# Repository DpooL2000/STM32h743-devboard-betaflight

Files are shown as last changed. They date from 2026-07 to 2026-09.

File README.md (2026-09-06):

# STM32H743 Flight Controller (Betaflight Target)

This repository provides an open-source engineering blueprint, custom target files, and a 4-layer hardware carrier board design to run standard Betaflight firmware on a generic **DevEBox STM32H743VIT6 development board**. 

Unlike commercial flight controllers that limit you to pre-configured layouts, utilizing a standard industrial developer board breaks open full control of the silicon. This project serves as a definitive architectural guide to overcoming severe bare-metal implementation bugs, remapping timers for advanced multi-rotor and actuator configurations, and running ultra-low latency PID loops on a highly affordable H7 platform.

## Hardware Architecture Manifest

<p align="center">

</p>

The target configuration files provided here are explicitly tailored and tested against the following component topology and hardware pin allocation mapping:

* **Microcontroller Core:** STM32H743VIT6 (ARM Cortex-M7 running at a 480MHz bus clock).
* **Primary IMU (SPI1):** BMI160 Gyro/Accelerometer module routed to native SPI1 pins:
  * `PA4` (Chip Select / CS)
  * `PA5` (SCK), `PA6` (MISO / SDI), `PA7` (MOSI / SDO)
  * Dedicated `PC4` EXTI hardware interrupt line synchronization.
* **Secondary IMU (SPI2):** BMI160 Gyro/Accelerometer module mapped onto isolated native SPI2 pins:
  * `PB12` (Chip Select / CS)
  * `PB13` (SCK), `PB14` (MISO / SDI), `PB15` (MOSI / SDO)
  * Dedicated `PD10` EXTI hardware interrupt line synchronization.
* **Barometer (I2C1):** BMP280 module routed to `PB8` (SCL) and `PB9` (SDA), configured via hardware jumpers on the breakout module to default I2C Address `0x76`.
* **Blackbox Telemetry:** High-speed onboard SDIO MicroSD card slot combined with an onboard QSPI external flash memory layer (`W25Q64JV`):
  * **SDIO (SDMMC1):** `PC12` (CK), `PD2` (CMD), `PC8` (D0), `PC9` (D1), `PC10` (D2), `PC11` (D3). Card detection is handled via software polling (`SDCD_PIN` set to `NONE`).
  * **QSPI:** `PB2` (CLK), `PB6` (CS), `PD11` (IO0), `PD12` (IO1), `PE2` (IO2), `PD13` (IO3).
* **Power Supply Module Integration (GM V1.0):** Integrated hardware telemetry lines from the buck-regulated external power module routed directly to the microcontroller's high-precision 16-bit ADC peripheral interface:
  * **Voltage Sensing (V_SENS):** Routed to analog input pin `PC1` (`ADC_VBAT_PIN`).
  * **Current Sensing (I_SENS):** Routed to analog input pin `PC0` (`ADC_CURR_PIN`).
* **Actuator Layout & Communications Matrix:**
  * **Motors (1–8):** `PA0` (Motor 1), `PA1` (Motor 2), `PA2` (Motor 3), `PA3` (Motor 4), `PB0` (Motor 5, timer remapped), `PB1` (Motor 6, timer remapped), `PD5` (Motor 7), `PD6` (Motor 8).
  * **Servos (1–4):** `PE5` (Servo 1), `PE6` (Servo 2), `PE1` (Servo 3, timer remapped), `PA15` (Servo 4, timer remapped).
  * **Serial Peripherals:** `UART1` (`PA9` TX, `PA10` RX) dedicated to Serial RX; `UART3` (`PD8` TX, `PD9` RX) assigned to ESC Telemetry; `UART6` (`PC6` / `PC7`) and `UART7` (`PE8` / `PE7`) exposed for general telemetry/VTX expansion.
  * **Peripherals:** Beeper output assigned to `PC2` (inverted configuration).

## System Layout & Renderings

**You can solder through hole Devboard to the SMD pads of this breakout board** giving you clear explansion over configured pins, Eight through hole pads have been left on the breakout board that you can align the Devboard on top of breakout board. and similarly solder the BMI160, BMP280 GY board on the breakout board make the work much easy, Though i havent route the circuit for each sensor on the breakout board itself, you can easily do it if you want, or you can just go with GY boards!!!. 

<p align="center">
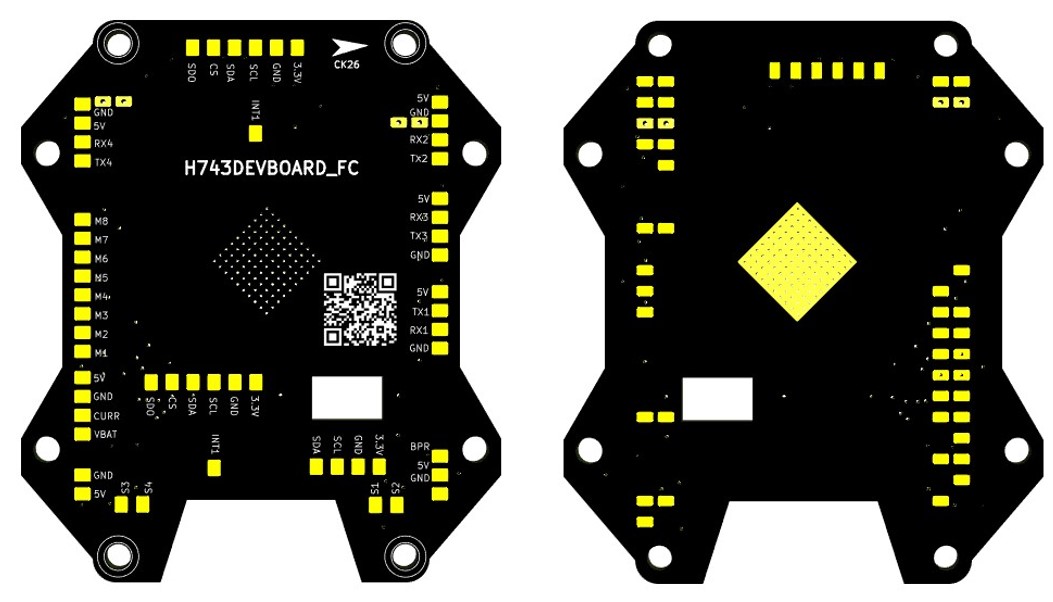
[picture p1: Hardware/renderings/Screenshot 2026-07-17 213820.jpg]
Carrier Board Layout

</p>

Detail guide on how the changes have been made is documented below, you can merge standard betaflight source code files with this. The project layout separates the custom hardware implementation from the localized Betaflight firmware tree structure as follows:

```text
├── Hardware/                      # Physical schematic and layout assets
│   ├── KiCad_Source/              # Raw .kicad_sch and .kicad_pcb project files
│   └── Renderings                 # Board images, schematics, and design references
|
├── STM32h743-devboard-betaflight/ # Target firmware deployment root
│   ├── src/                       # Localized Betaflight source tree overlays
│   │   ├── config/
│   │   │   └── configs/
│   │   │       └── DEVBOARD/
│   │   │           └── config.h   # Master firmware target pin mapping definitions
│   │   ├── main/
│   │   │   ├── drivers/
│   │   │   │   └── accgyro/
│   │   │   │       └── pios_bmi160.c
│   │   └── platform/
│   │       └── STM32/
│   │           └── startup/
│   │               └── system_stm32h7xx.c
```

---

# 1. Bare-Metal Hardware Troubleshooting

Bringing Betaflight up on standard industrial development boards reveals discrepancies between consumer flight controllers and raw silicon layouts. Below is the technical documentation of the critical bare-metal failures encountered during hardware debugging, along with their permanent firmware solutions.

### Bug 1.1: 25MHz HSE Crystal & PLL1 Clock Configuration Failures

**The Bug:**
Standard Betaflight STM32H7 codebases are optimized for 8MHz or 24MHz external crystals. The DevEBox hardware utilizes a 25MHz HSE. Applying default configuration multipliers caused the internal voltage-controlled oscillator (VCO) to hit 3000MHz, which drastically exceeds the 960MHz hardware limit. This caused the phase-locked loop engine to fail, triggering an infinite safety reset loop inside `HandleStuckSysTick()`.

**The Structural Fix:**
The internal clock structures (`pll1ConfigRevY` and `pll1ConfigRevV`) inside `src/platform/STM32/startup/system_stm32h7xx.c` must be rewritten to scale the 25MHz crystal safely:

```c
// Adjusted clock parameters for a stable 480MHz SYSCLK
pllConfig_t pll1ConfigRevV = {
    .clockMhz = 480,
    .m = 5,
    .n = 192,
    .p = 2,
    .q = 8,
    .r = 5,
    .vos = PWR_REGULATOR_VOLTAGE_SCALE0,
    .vciRange = RCC_PLL1VCIRANGE_2,
};
```

### Bug 1.2: Missing HSI48 Internal Oscillator & PLL3 USB Solution

**The Bug:**
To establish a stable USB Virtual COM Port (VCP), the STM32 USB peripheral requires a 48MHz clock stream. Betaflight natively attempts to activate the internal HSI48 oscillator. However, hardware debugging proved the DevEBox completely ignores `RCC_CR_HSI48ON` register writes, leaving the USB peripheral without a clock signal and failing to enumerate.

**The Structural Fix:**
Bypass the dead internal HSI48 circuit and synthesize a 48MHz USB clock using the primary 25MHz HSE crystal routed through the PLL3 engine.

Define the macro override in your local `config.h`:

```c
#define USE_USB_CLOCK_PLL3
```

Apply these specific division parameters inside the USB initialization block of `system_stm32h7xx.c` to step the 25MHz HSE down to an exact 48MHz envelope:

```c
PLL3M = 5,  // 25MHz HSE / 5 = 5MHz reference
PLL3N = 48, // 5MHz * 48 = 240MHz VCO3
PLL3Q = 5   // 240MHz VCO3 / 5 = 48MHz USB output clock
```

### Bug 1.3: Dual BMI160 Cold-Boot Lockout & DMA Collision

**The Bug:**
When booting two BMI160 gyroscopes simultaneously via SPI1 and SPI2, the secondary gyro regularly fails to lock DMA. 
1. **DMA Hijacking:** `DSHOT_BITBANG_1` was statically allocated to `DMA1 Stream 0`, forcing the H7 DMAMUX auto-allocator to starve `SPI1_TX` of a continuous stream, resulting in CPU-polling mode (missing the `dma` flag).
2. **State Variable Collision:** The driver code (`pios_bmi160.c`) utilized global state variables (`BMI160InitDone`). When Gyro 1 initialized, it set the variable to true, which caused Gyro 2 to completely bypass its configuration logic on cold boots.

**The Structural Fix:**
First, bypass the DMAMUX auto-allocator by hardcoding explicit DMA offsets in your local `config.h`:

```c
// Force dual-gyro initialization on boot
#define DEFAULT_GYRO_TO_USE          GYRO_CONFIG_USE_GYRO_BOTH

// Explicit SPI DMA Stream Offsets (Bypasses DMAMUX Auto-Allocation Collisions)
#define SPI1_TX_DMA_OPT              5  // Maps to DMA1 Stream 4
#define SPI1_RX_DMA_OPT              2  // Maps to DMA1 Stream 1
#define SPI2_TX_DMA_OPT              3  // Maps to DMA1 Stream 2
#define SPI2_RX_DMA_OPT              4  // Maps to DMA1 Stream 3
```

Second, eliminate the shared global states within the driver. Inside `src/main/drivers/accgyro/pios_bmi160.c`, delete the global boolean variables (`BMI160InitDone` and `BMI160Detected`) and replace the initialization functions with this independent configuration logic:

```c
uint8_t bmi160Detect(const extDevice_t *dev)
{
    // Toggle CS to activate SPI
    spiWrite(dev, 0xFF);
    delay(100); // Give SPI some time to start up

    // Check the chip ID
    if (spiReadRegMsk(dev, BMI160_REG_CHIPID) != 0xd1) {
        return MPU_NONE;
    }

    return BMI_160_SPI;
}

static void BMI160_Init(const extDevice_t *dev)
{
    /* Configure the BMI160 Sensor */
    if (BMI160_Config(dev) != 0) {
        return;
    }

    bool do_foc = false;
    /* Perform fast offset compensation if requested */
    if (do_foc) {
        BMI160_do_foc(dev);
    }
}
```

---

# 2. Firmware Source Tree Modification & Compilation Guide

To replicate this build and compile the custom DevEBox target, follow these exact modifications within the Betaflight source tree.

### 1. Target Directory Setup
Create a new directory named `DEVBOARD` inside `src/main/config/configs/`. 
Place your custom `config.h` files into this new folder.

### 2. Core Source Modifications
You must manually patch the following core Betaflight files to implement the bare-metal hardware fixes detailed in Section 1:

**File: `src/platform/STM32/startup/system_stm32h7xx.c`**
* Locate the `pll1ConfigRevY` and `pll1ConfigRevV` structures. Update the multipliers for the 25MHz HSE: set `.m = 25`, `.n = 400`, and `.p = 2`.
* Locate the USB clock configuration block. Comment out the `HSI48` initialization and insert the PLL3 dividers: `PLL3M = 5`, `PLL3N = 48`, and `PLL3Q = 5`.
* Locate the `SystemInit()` function and comment out the `memProtConfigure()` call to prevent early boot memory protection faults on this specific developer silicon.

**File: `src/main/drivers/accgyro/pios_bmi160.c`**
* Locate the `bmi160Detect()` and `BMI160_Init()` functions.
* Delete the `BMI160InitDone` and `BMI160Detected` global variables and paste the updated initialization block provided in Section 1.3 to ensure both gyros initialize independently and acquire DMA locks.

# 3. Compilation & Flashing

### Step 1: Clone Betaflight with all submodules (prevents empty config/configs directories)
```bash
git clone --recurse-submodules [https://github.com/betaflight/betaflight.git](https://github.com/betaflight/betaflight.git)
cd betaflight
```

### (Optional) If you already cloned Betaflight without submodules, run this to fetch them:
```bash
git submodule update --init --recursive
```

### Step 2: Copy your custom DEVBOARD target files into the local Betaflight tree

Manually paste your DEVBOARD config.h into `src/config/configs/DEVBOARD/` and patch the target core files.

### Step 3: Clean and compile the unified DEVBOARD target
```bash
make clean
make DEVBOARD -j$(nproc)
```

Once compilation is complete, flash the resulting `.hex` file to your STM32H743 via STM32CubeProgrammer or the Betaflight Configurator while the board is in DFU mode. For DFU mode you need to connect `BT0` to `3.3V` (you can find these pins near the SWT pins).

---

# 4. Power Distribution & Critical Sensor Calibration

### 1. Power Supply Topology
This target configuration assumes the system is powered by an external step-down switching regulator delivering a stable 5V rail to the developer board. The onboard AMS1117-3.3 LDO regulator drops this input to 3.3V for the STM32H7 core and sensor buses, providing robust immunity against heavy Li-ion voltage sag down to a structural threshold of 4.4V.

### 2. Telemetry & ADC Scaling (User Calibration Required)
To achieve real-time battery status monitoring, the analog Voltage (V_SENS) and Current (I_SENS) lines from your power module must be routed to the microcontroller's ADC pins (`PC1` for Voltage, `PC0` for Current).

**Mandatory Calibration Protocol:**
Do not rely blindly on stock software scale parameters. Every power module utilizes different internal resistor divider networks, and component manufacturing tolerances fluctuate. 

As a structural baseline, this target defaults to our specific hardware mapping (a GM V1.0 power module with a 10.76:1 voltage divider):

```text
set vbat_scale = 108
set current_meter_scale = 85
set current_meter_offset = -3500
save
```

⚠️ Before your first test flight, you must manually calibrate your hardware:

1. Connect your fully assembled battery pack to the drone and measure the raw voltage at the main XT60 bus using a calibrated bench digital multimeter.
2. Boot into the Betaflight Configurator GUI and check the reported voltage reading on the main Setup dashboard.
3. Micro-adjust the `vbat_scale` numerical values up or down in the CLI tab (or the Power & Battery tab) until the software telemetry read-out matches your multimeter's hardware voltage precisely.
4. Perform a similar verification for the current sensor by measuring the draw of a known load and adjusting the `current_meter_scale` accordingly.

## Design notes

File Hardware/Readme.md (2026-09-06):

# Mark 4 Long-Range Cruiser (10-Inch) - Build & Tuning Specifications

This document outlines the complete hardware architecture, propulsion system, and Betaflight tuning parameters for the 10-inch Mark 4 endurance cruiser. The PID and filter configurations are specifically optimized for smooth, long-range flight dynamics and heavy payload stability, utilizing a custom STM32H743 flight controller.

<div align="center">
WhatsApp Image 2026-09-06 at 21 29 51
</div>

## 1. Hardware & Propulsion Architecture
* **Frame:** Mark 4 (10-inch configuration)
* **Target AUW (All-Up Weight):** ~1.5 kg
* **Motors:** 950KV Brushless
* **Propellers:** 9450 
* **Power Source:** Custom 4S3P Lithium-Ion Pack (Samsung INR35E 18650 cells)
* **Flight Controller MCU:** DevEBox STM32H743VIT6 (ARM Cortex-M7 @ 480MHz)
* **Firmware:** Betaflight 2026.6.0-alpha (Custom Target)

## 2. Sensor & Avionics Package
* **Primary/Secondary IMU:** Dual BMI160 Gyro/Accelerometers (Running on independent SPI1 & SPI2 buses with dedicated DMA streams)
* **Barometer:** BMP280 (I2C)
* **Magnetometer:** QMC5883L (I2C, mapped for True North alignment)
* **GPS:** UBLOX M8 (UART6, 57600 baud)
* **Blackbox:** High-speed onboard SDIO MicroSD (FAT32, 32KB clusters) logging at 458Hz

---

## 3. PID Tuning Profile

These PID values are tailored for the high inertia of a 10-inch frame. D-gains are set slightly higher on Pitch to combat the larger moment of inertia, while Feedforward is kept moderate for smooth, cinematic stick feel.



**Basic / Acro**
* **ROLL:** P = 33 | I = 45 | D = 50 | D Max = 55 | FF = 30
* **PITCH:** P = 38 | I = 50 | D = 60 | D Max = 66 | FF = 30
* **YAW:** P = 35 | I = 60 | D = 25 | D Max = 30 | FF = 30

**PID Controller Settings**
* **I Term Relax:** On | Axes: RPY | Type: Setpoint | Cutoff: 15
* **Anti Gravity:** On | Gain: 8.0
* **Dynamic Damping:** Gain: 37 | Advance: 20
* **TPA:** Mode: D | TPA Rate: 65% | Breakpoint: 1350
* **Feedforward:** Jitter Reduction: 11 | Smoothness: 45 | Averaging: 2 Point | Boost: 15 | Max Rate Limit: 90
* **Throttle Boost:** 5
* **Vbat Sag Compensation:** 10%

---

## 4. Filter Settings

Given the lower frequency vibrations generated by 10-inch props, the global filter multipliers are shifted to prioritize cleaner gyro data over absolute minimal latency.



**Global Multipliers**
* **Gyro Filter Multiplier:** 0.50
* **D Term Filter Multiplier:** 1.10

**Gyro Filters**
* **Gyro Lowpass 1:** STATIC | Cutoff: 125Hz | PT1
* **Gyro Lowpass 2:** STATIC | Cutoff: 250Hz | PT1
* **Dynamic Notch Filter:** Count: 3 | Q factor: 250 | Min Freq: 60Hz | Max Freq: 350Hz

**D-Term Filters**
* **D Term Lowpass 1:** DYNAMIC | Min Cutoff: 82Hz | Max Cutoff: 165Hz | Curve: 5 | PT1
* **D Term Lowpass 2:** STATIC | Cutoff: 165Hz | PT1
* **Yaw Lowpass Filter:** STATIC | Cutoff: 100Hz

<div align="center">
  <video src="https://github.com/user-attachments/assets/aab0e29f-c0ef-4e6e-a5ba-c4611601c329" controls="controls" width="100%"></video>
</div>

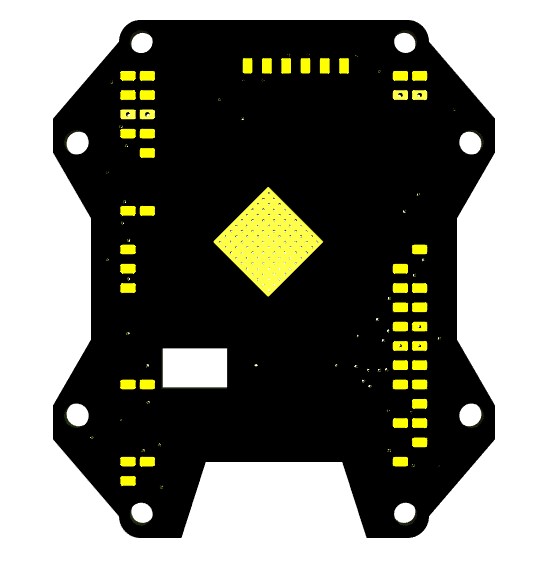
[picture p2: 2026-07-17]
Hardware/renderings/Screenshot 2026-07-17 210930.jpg

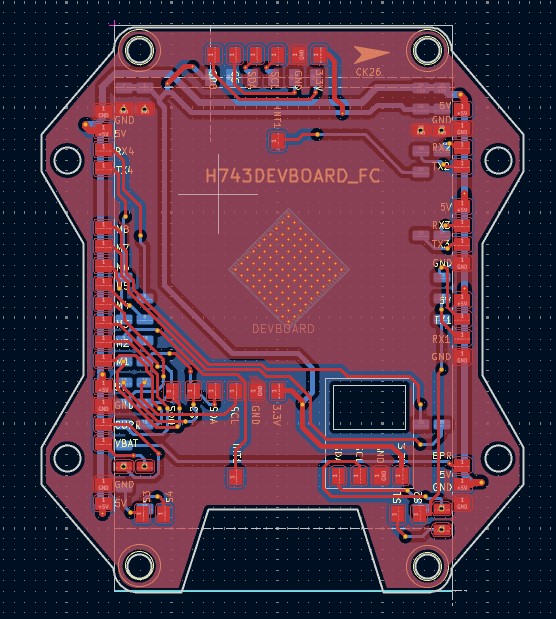
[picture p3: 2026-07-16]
Hardware/renderings/Screenshot 2026-07-16 223007.jpg

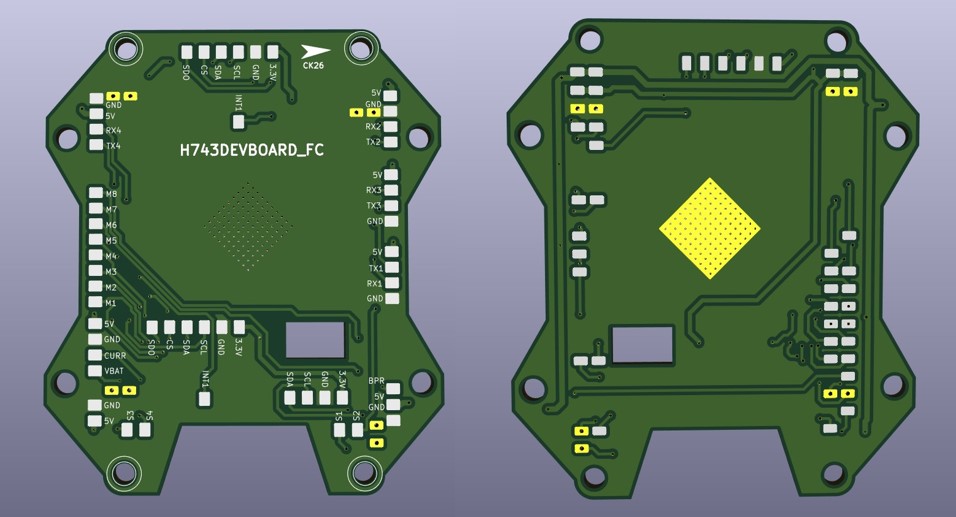
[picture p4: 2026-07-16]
Hardware/renderings/Screenshot 2026-07-16 230226.jpg

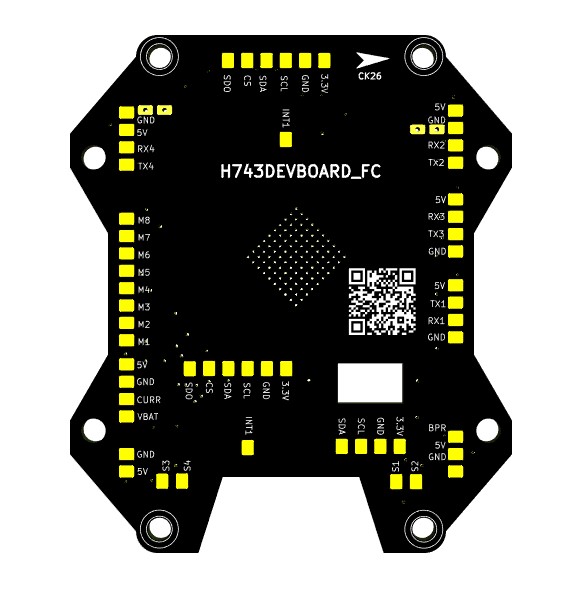
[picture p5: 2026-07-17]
Hardware/renderings/Screenshot 2026-07-17 210903.jpg

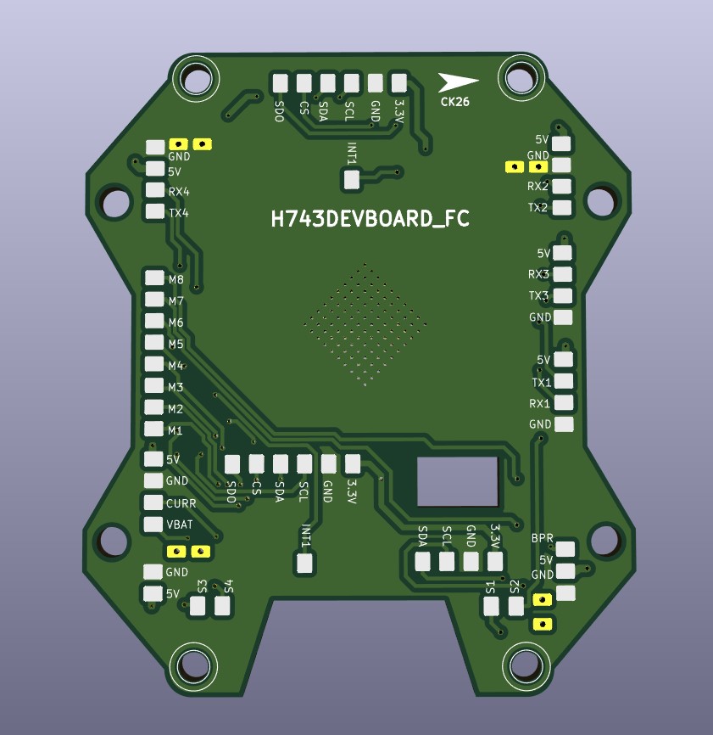
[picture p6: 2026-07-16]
Hardware/renderings/Screenshot 2026-07-16 223036.jpg

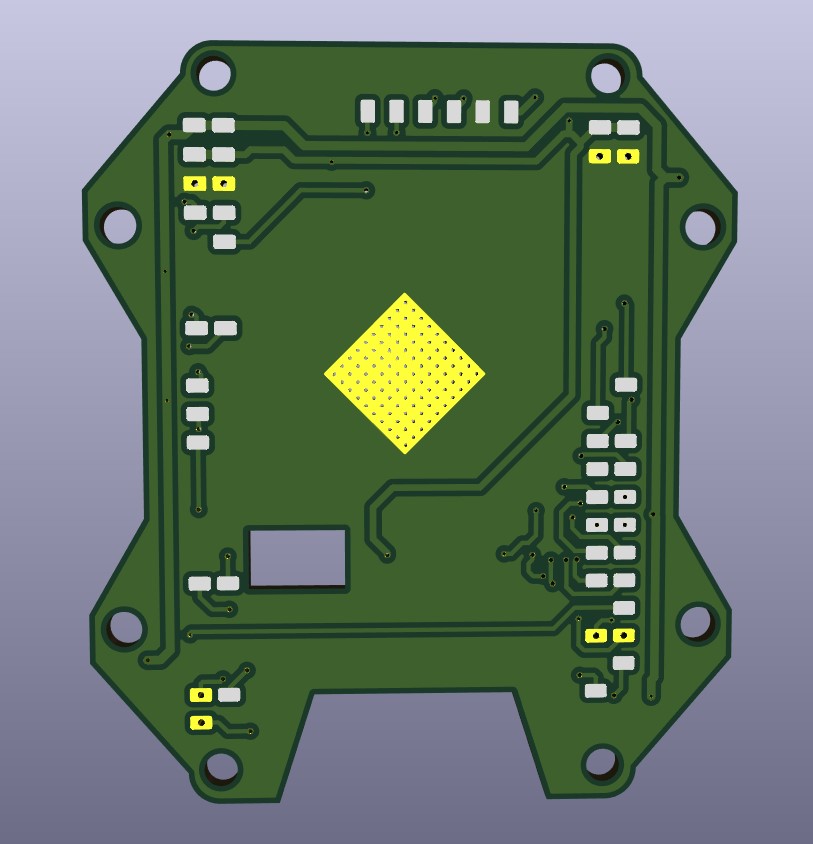
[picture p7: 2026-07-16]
Hardware/renderings/Screenshot 2026-07-16 223053.jpg

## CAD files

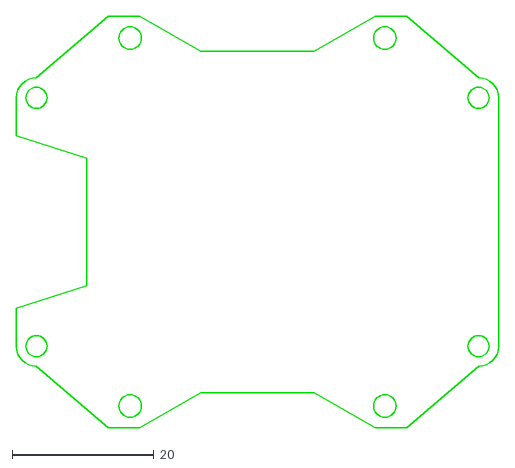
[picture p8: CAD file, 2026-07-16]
Hardware/ki CAD files/BREAKOUT.dxf
68.2 x 58.2

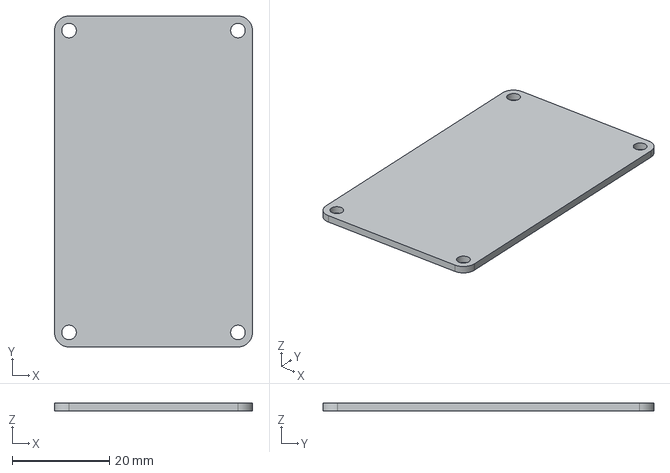
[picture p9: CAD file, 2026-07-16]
Hardware/ki CAD files/DUMMY_H743.stp
40.8 x 68.2 x 1.60 mm

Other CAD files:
Hardware/ki CAD files/BREAKOUT.psm

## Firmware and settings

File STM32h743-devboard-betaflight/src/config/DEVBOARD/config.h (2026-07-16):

#pragma once

#define FC_TARGET_MCU                STM32H743

#define BOARD_NAME                   DEVBOARD
#define MANUFACTURER_ID              USER

// --- CLOCK & USB ---
#ifndef HSE_VALUE
#define HSE_VALUE                    ((uint32_t)25000000)
#endif
#define SYSTEM_HSE_MHZ               25

#define USE_USB_CDC
#define USB_DETECT_PIN               NONE
#define USE_USB_CLOCK_PLL3           // PLL3 provides 48 MHz USB clock from HSE

// --- SENSORS: BMI160 (SPI1) & BMP280 (I2C1) ---
#define USE_ACC
#define USE_GYRO
#define USE_ACCGYRO_BMI160
#define USE_ACC_SPI_BMI160
#define USE_GYRO_SPI_BMI160

#define USE_BARO
#define USE_BARO_BMP280

// BMI160 on SPI1
#define GYRO_1_SPI_INSTANCE          SPI1
#define GYRO_1_CS_PIN                PA4
#define GYRO_1_EXTI_PIN              PC4
#define GYRO_1_ALIGN                 CW0_DEG
#define DEFAULT_GYRO_TO_USE          GYRO_CONFIG_USE_GYRO_1


// BMI160 on SPI2 (Second Gyro)
#define GYRO_2_SPI_INSTANCE          SPI2
#define GYRO_2_CS_PIN                PB12
#define GYRO_2_ALIGN                 CW0_DEG
#define GYRO_2_EXTI_PIN              PD10    

// BMP280 on I2C1 (PB8, PB9)
#define BARO_I2C_INSTANCE            I2CDEV_1
#define I2C1_SCL_PIN                 PB8
#define I2C1_SDA_PIN                 PB9

// --- FLASH MEMORY (QSPI) ---
#define USE_QUADSPI
#define USE_QUADSPI_DEVICE_1         // Activates the default configuration array structure
#define USE_FLASH_QSPI
#define USE_FLASH_W25Q64JV

// Pin definitions matching the quadSpiDefaultConfig macro targets exactly
#define QUADSPI1_SCK_PIN             PB2
#define QUADSPI1_BK1_CS_PIN          PB6
#define QUADSPI1_BK1_IO0_PIN         PD11
#define QUADSPI1_BK1_IO1_PIN         PD12
#define QUADSPI1_BK1_IO2_PIN         PE2
#define QUADSPI1_BK1_IO3_PIN         PD13

// --- SDCARD (SDMMC1) ---
#define USE_SDCARD
#define USE_SDCARD_SDIO
#define SDIO_DEVICE                  SDIODEV_1
#define SDIO_CK_PIN                  PC12
#define SDIO_CMD_PIN                 PD2
#define SDIO_D0_PIN                  PC8
#define SDIO_D1_PIN                  PC9
#define SDIO_D2_PIN                  PC10
#define SDIO_D3_PIN                  PC11
#define SDCD_PIN                     NONE  // Rely on software polling for card detection

#define DEFAULT_BLACKBOX_DEVICE      BLACKBOX_DEVICE_SDCARD
//#define DEFAULT_BLACKBOX_DEVICE      BLACKBOX_DEVICE_FLASH

// --- ADC ---
#define USE_ADC
#define ADC_VBAT_PIN                 PC1
#define ADC_CURR_PIN                 PC0
#define ADC_RSSI_PIN                 PC5 // not used i dont remember the reason but we discussed somewhere
#define DEFAULT_CURRENT_METER_SOURCE CURRENT_METER_ADC
#define DEFAULT_VOLTAGE_METER_SOURCE VOLTAGE_METER_ADC
#define DEFAULT_CURRENT_METER_SCALE  120
#define DEFAULT_VOLTAGE_METER_SCALE  108

// --- PINS: SPI & I2C ---
#define SPI1_SCK_PIN                 PA5
#define SPI1_SDI_PIN                 PA6
#define SPI1_SDO_PIN                 PA7

#define SPI2_SCK_PIN                 PB13
#define SPI2_SDI_PIN                 PB14
#define SPI2_SDO_PIN                 PB15

// I2C2 is free
#define I2C2_SCL_PIN                 PB10
#define I2C2_SDA_PIN                 PB11

// --- PINS: UARTS ---
// UART1 – used for Serial RX (receiver)
#define UART1_TX_PIN                 PA9
#define UART1_RX_PIN                 PA10

// UART3 – used for ESC telemetry
#define UART3_TX_PIN                 PD8
#define UART3_RX_PIN                 PD9

#define UART6_TX_PIN                 PC6
#define UART6_RX_PIN                 PC7

#define UART7_TX_PIN                 PE8
#define UART7_RX_PIN                 PE7


#define SERIALRX_UART                SERIAL_PORT_UART1
#define ESC_SENSOR_UART              SERIAL_PORT_USART3

// --- PINS: MISC ---
#define BEEPER_PIN                   PC2
#define BEEPER_INVERTED

// --- MOTOR & SERVO ---
// Motors 1-4 stay on original pins
#define MOTOR1_PIN                   PA0
#define MOTOR2_PIN                   PA1
#define MOTOR3_PIN                   PA2
#define MOTOR4_PIN                   PA3

// Motor5 moved to PB0 (free, timer capable) – original PD12 used by QSPI IO1
#define MOTOR5_PIN                   PB0
// Motor6 moved to PB1 (free, timer capable) – original PD13 used by QSPI IO3
#define MOTOR6_PIN                   PB1
#define MOTOR7_PIN                   PD5
#define MOTOR8_PIN                   PD6

// Servo1/2 stay on original pins
#define SERVO1_PIN                   PE5
#define SERVO2_PIN                   PE6
// Servo3 moved to PE1 (free) – original PC8 used by SDIO DAT0
#define SERVO3_PIN                   PE1
// Servo4 moved to PA15 (free) – original PC9 used by SDIO DAT1
#define SERVO4_PIN                   PA15

// --- TIMERS & DMA ---
// Remapped motor/servo timers to new free pins
// Betaflight Format: TIMER_PIN_MAP(index, pin, timer_number, channel_index)
// Channel index is 0-based (0 = CH1, 1 = CH2, 2 = CH3, 3 = CH4)

#define TIMER_PIN_MAPPING                                             \
    TIMER_PIN_MAP( 0,  PA0,  1,  0) /* TIM1_CH1 */                    \
    TIMER_PIN_MAP( 1,  PA1,  1,  1) /* TIM1_CH2 */                    \
    TIMER_PIN_MAP( 2,  PA2,  1,  2) /* TIM1_CH3 */                    \
    TIMER_PIN_MAP( 3,  PA3,  1,  3) /* TIM1_CH4 */                    \
    TIMER_PIN_MAP( 4,  PB0,  2,  1) /* TIM2_CH2 - Replaces Motor 5 */ \
    TIMER_PIN_MAP( 5,  PB1,  2,  2) /* TIM2_CH3 - Replaces Motor 6 */ \
    TIMER_PIN_MAP( 6,  PE1,  3,  0) /* TIM3_CH1 - Replaces Servo 3 */ \
    TIMER_PIN_MAP( 7, PA15,  3,  1) /* TIM3_CH2 - Replaces Servo 4 */

#define ADC1_DMA_OPT                 9
#define ADC3_DMA_OPT                 10
#define TIMUP3_DMA_OPT               11
#define TIMUP4_DMA_OPT               12
#define TIMUP5_DMA_OPT               13
#define DEFAULT_DSHOT_BITBANG        DSHOT_BITBANG_ON

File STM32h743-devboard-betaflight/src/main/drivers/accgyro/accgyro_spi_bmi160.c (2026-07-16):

/**
 ******************************************************************************
 * @addtogroup PIOS PIOS Core hardware abstraction layer
 * @{
 * @addtogroup PIOS_BMI160 BMI160 Functions
 * @brief Hardware functions to deal with the 6DOF gyro / accel sensor
 * @{
 *
 * @file       pios_bmi160.c
 * @author     dRonin, http://dRonin.org/, Copyright (C) 2016
 * @brief      BMI160 Gyro / Accel Sensor Routines
 * @see        The GNU Public License (GPL) Version 3
 ******************************************************************************/

/*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
 * Additional note on redistribution: The copyright and license notices above
 * must be maintained in each individual source file that is a derivative work
 * of this source file; otherwise redistribution is prohibited.
 */

#include <stdbool.h>
#include <stdint.h>
#include <stdlib.h>
#include <string.h>

#include "platform.h"

#ifdef USE_ACCGYRO_BMI160

#include "drivers/accgyro/accgyro.h"
#include "drivers/accgyro/accgyro_spi_bmi160.h"
#include "drivers/bus_spi.h"
#include "drivers/exti.h"
#include "drivers/io.h"
#include "drivers/nvic.h"
#include "drivers/sensor.h"
#include "drivers/system.h"
#include "drivers/time.h"

#include "sensors/gyro.h"

// 10 MHz max SPI frequency
#define BMI160_MAX_SPI_CLK_HZ 10000000

/* BMI160 Registers */
#define BMI160_REG_CHIPID 0x00
#define BMI160_REG_PMU_STAT 0x03
#define BMI160_REG_GYR_DATA_X_LSB 0x0C
#define BMI160_REG_ACC_DATA_X_LSB 0x12
#define BMI160_REG_STATUS 0x1B
#define BMI160_REG_TEMPERATURE_0 0x20
#define BMI160_REG_ACC_CONF 0x40
#define BMI160_REG_ACC_RANGE 0x41
#define BMI160_REG_GYR_CONF 0x42
#define BMI160_REG_GYR_RANGE 0x43
#define BMI160_REG_INT_EN1 0x51
#define BMI160_REG_INT_OUT_CTRL 0x53
#define BMI160_REG_INT_MAP1 0x56
#define BMI160_REG_FOC_CONF 0x69
#define BMI160_REG_CONF 0x6A
#define BMI160_REG_OFFSET_0 0x77
#define BMI160_REG_CMD 0x7E

/* Register values */
#define BMI160_PMU_CMD_PMU_ACC_NORMAL 0x11
#define BMI160_PMU_CMD_PMU_GYR_NORMAL 0x15
#define BMI160_INT_EN1_DRDY 0x10
#define BMI160_INT_OUT_CTRL_INT1_CONFIG 0x0A
#define BMI160_REG_INT_MAP1_INT1_DRDY 0x80
#define BMI160_CMD_START_FOC 0x03
#define BMI160_CMD_PROG_NVM 0xA0
#define BMI160_REG_STATUS_NVM_RDY 0x10
#define BMI160_REG_STATUS_FOC_RDY 0x08
#define BMI160_REG_CONF_NVM_PROG_EN 0x02
#define BMI160_VAL_GYRO_CONF_BWP_OSR4 0x00
#define BMI160_VAL_GYRO_CONF_BWP_OSR2 0x10
#define BMI160_VAL_GYRO_CONF_BWP_NORM 0x20
#define BMI160_VAL_ACC_CONF_BWP_OSR4 0x00
#define BMI160_VAL_ACC_CONF_BWP_OSR2 0x10
#define BMI160_VAL_ACC_CONF_BWP_NORM 0x20
#define BMI160_VAL_ACC_CONF_US_HP 0x00

// Need to see at least this many interrupts during initialisation to confirm EXTI connectivity
#define GYRO_EXTI_DETECT_THRESHOLD 1000

// Global Variables
static volatile bool BMI160InitDone = false;
static volatile bool BMI160Detected = false;

//! Private functions
static int32_t BMI160_Config(const extDevice_t *dev);
static int32_t BMI160_do_foc(const extDevice_t *dev);

uint8_t bmi160Detect(const extDevice_t *dev)
{
    if (BMI160Detected) {
        return BMI_160_SPI;
    }

    // Force SPI mode: toggle CS low then high to wake GY-BMI160 out of I2C mode
    IO_t csPin = dev->busType_u.spi.csnPin; // <--- FIXED: It is already an IO_t object!
    if (csPin) {
        IOWrite(csPin, true);       // high
        delayMicroseconds(10);
        IOWrite(csPin, false);      // low
        delayMicroseconds(10);
        IOWrite(csPin, true);       // high

        // Give the BMI160 SPI interface 10ms to stabilize
        delayMicroseconds(10000);
    }

    // Check the chip ID
    if (spiReadRegMsk(dev, BMI160_REG_CHIPID) != 0xd1) {
        return MPU_NONE;
    }

    BMI160Detected = true;

    return BMI_160_SPI;
}

/**
 * @brief Initialize the BMI160 6-axis sensor.
 * @return 0 for success, -1 for failure to allocate, -10 for failure to get irq
 */
static void BMI160_Init(const extDevice_t *dev)
{
    if (BMI160InitDone || !BMI160Detected) {
        return;
    }

    /* Configure the BMI160 Sensor */
    if (BMI160_Config(dev) != 0) {
        return;
    }

    bool do_foc = false;

    /* Perform fast offset compensation if requested */
    if (do_foc) {
        BMI160_do_foc(dev);
    }

    BMI160InitDone = true;
}

static uint8_t getBmiOsrMode(void)
{
    switch(gyroConfig()->gyro_hardware_lpf) {
        case GYRO_HARDWARE_LPF_NORMAL:
            return BMI160_VAL_GYRO_CONF_BWP_OSR4;
        case GYRO_HARDWARE_LPF_OPTION_1:
            return BMI160_VAL_GYRO_CONF_BWP_OSR2;
        case GYRO_HARDWARE_LPF_OPTION_2:
            return BMI160_VAL_GYRO_CONF_BWP_NORM;
#ifdef USE_GYRO_DLPF_EXPERIMENTAL
        case GYRO_HARDWARE_LPF_EXPERIMENTAL:
            return BMI160_VAL_GYRO_CONF_BWP_NORM;
#endif
        default:
            return BMI160_VAL_GYRO_CONF_BWP_OSR4;
    }
}

/**
 * @brief Configure the sensor
 */
static int32_t BMI160_Config(const extDevice_t *dev)
{
    // Set normal power mode for gyro and accelerometer
    spiWriteReg(dev, BMI160_REG_CMD, BMI160_PMU_CMD_PMU_GYR_NORMAL);
    delay(100); // can take up to 80ms

    spiWriteReg(dev, BMI160_REG_CMD, BMI160_PMU_CMD_PMU_ACC_NORMAL);
    delay(5); // can take up to 3.8ms

    // Verify that normal power mode was entered
    uint8_t pmu_status = spiReadRegMsk(dev, BMI160_REG_PMU_STAT);
    if ((pmu_status & 0x3C) != 0x14) {
        return -3;
    }

    // Set odr and ranges
    // Set acc_us = 0 & acc_bwp = 0b001 for high performance and OSR2 mode
    spiWriteReg(dev, BMI160_REG_ACC_CONF, BMI160_VAL_ACC_CONF_US_HP | BMI160_VAL_ACC_CONF_BWP_OSR2 | BMI160_ODR_800_Hz);
    delay(1);

    spiWriteReg(dev, BMI160_REG_GYR_CONF, getBmiOsrMode() | BMI160_ODR_3200_Hz);
    delay(1);

    spiWriteReg(dev, BMI160_REG_ACC_RANGE, BMI160_RANGE_8G);
    delay(1);

    spiWriteReg(dev, BMI160_REG_GYR_RANGE, BMI160_RANGE_2000DPS);
    delay(1);

    // Enable offset compensation
    uint8_t val = spiReadRegMsk(dev, BMI160_REG_OFFSET_0);
    spiWriteReg(dev, BMI160_REG_OFFSET_0, val | 0xC0);

    // Enable data ready interrupt
    spiWriteReg(dev, BMI160_REG_INT_EN1, BMI160_INT_EN1_DRDY);
    delay(1);

    // Enable INT1 pin
    spiWriteReg(dev, BMI160_REG_INT_OUT_CTRL, BMI160_INT_OUT_CTRL_INT1_CONFIG);
    delay(1);

    // Map data ready interrupt to INT1 pin
    spiWriteReg(dev, BMI160_REG_INT_MAP1, BMI160_REG_INT_MAP1_INT1_DRDY);
    delay(1);

    return 0;
}
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

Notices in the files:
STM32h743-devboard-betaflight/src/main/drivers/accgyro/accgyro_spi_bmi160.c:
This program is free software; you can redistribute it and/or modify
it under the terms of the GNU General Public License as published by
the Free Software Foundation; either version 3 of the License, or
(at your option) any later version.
